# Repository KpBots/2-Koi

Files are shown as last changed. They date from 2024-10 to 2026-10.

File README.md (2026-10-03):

# 2-Koi · Mini-sumo

**2-Koi quedó segundo en la competición de mini-sumo de la OSHWDem 2024.** En esta ocasión se adapta su firmware a la [normativa de 2026](https://rules.oshwdem.org/loita_sumo_es): el juez inicia y detiene el robot por infrarrojos y el movimiento comienza sin la antigua espera de cinco segundos.

El programa se carga en un Arduino Nano con ATmega328P. El módulo IRStart recibe y decodifica el mando IR; el Nano solo lee el estado mantenido de su salida `OUT`. Por tanto, el IRStart debe tener ya cargados los códigos START y STOP adecuados. El programa del Nano no decodifica RC05 ni configura el módulo.

## Conexiones

| Componente | Pin del Nano | Uso |
| --- | --- | --- |
| Sensor de presencia | A0 | Medida analógica del oponente |
| IRStart VCC | A1 | Salida HIGH que alimenta el módulo |
| IRStart GND | A2 | Salida LOW que hace de masa |
| IRStart OUT | A3 | Entrada digital; LOW = parado, HIGH = activo |
| Sensor de borde izquierdo | D7 | Entrada activa en LOW |
| Sensor de borde derecho | D8 | Entrada activa en LOW |
| Selector derecho | D6 | Entrada con pull-up |
| Común de los selectores | D5 | Salida LOW |
| Selector frontal | D4 | Entrada con pull-up |
| Selector izquierdo | D2 | Entrada con pull-up |
| Motor izquierdo | D9 y D10 | Entradas del puente H |
| Motor derecho | D3 y D11 | Entradas del puente H |

Los selectores se activan al unir su entrada con el común D5. El interruptor izquierdo está montado con la orientación física inversa a la esperada: comprueba su posición por la maniobra que realiza, no por la marca ON/OFF de la carcasa. Para que un cable `OUT` suelto no deje A3 flotante, se puede añadir una resistencia externa de 10 kΩ entre A3 y GND.

## Elegir la estrategia de salida

Coloca los selectores **antes de enviar START**. El programa los lee al comenzar cada asalto. La maniobra inicial dura solo el tiempo indicado; después el robot pasa a buscar al oponente.

| Selectores activados | Primera maniobra tras START |
| --- | --- |
| Izquierdo + derecho | Retrocede 300 ms |
| Izquierdo | Gira sobre sí mismo a la izquierda 150 ms |
| Frontal | Avanza 150 ms |
| Derecho | Gira sobre sí mismo a la derecha 120 ms |
| Ninguno | Empieza a buscar inmediatamente |

Si activas varios selectores, la prioridad es: **izquierdo + derecho**, luego **izquierdo**, luego **frontal** y, por último, **derecho**. Por ejemplo, frontal + derecho ejecuta la salida frontal. El selector frontal no modifica la salida hacia atrás si están activados ambos laterales.

Durante la búsqueda, el robot avanza hacia un objeto detectado aproximadamente entre 20 y 200 mm. Si no detecta ninguno, alterna al azar giros a izquierda y derecha. El LED integrado del Nano se enciende mientras detecta al oponente. La maniobra inicial se completa antes de atender los sensores de borde; después, un sensor de borde activo tiene prioridad sobre la búsqueda: el robot retrocede 100 ms y gira para alejarse del borde. STOP sigue teniendo prioridad en todo momento.

## Arranque, parada y carga

1. Abre `2-Koi/2-Koi.ino` en Arduino IDE. Selecciona **Arduino Nano**, ATmega328P y el procesador/bootloader que corresponda a tu placa; después carga el programa por USB.
2. Para la primera prueba, levanta las ruedas del suelo. Enciende el robot con IRStart conectado: debe quedarse parado hasta recibir START. Si el Nano arranca cuando `OUT` ya está en HIGH, esperará a ver primero un estado LOW y luego otro START.
3. Ajusta los selectores y envía START con el mando del juez, un mando compatible o la app configurada para los códigos del IRStart. Observa las ruedas justo al arrancar: la estrategia solo dura entre 120 y 300 ms; después comienza la búsqueda.
4. Envía STOP mientras se mueve: los motores deben detenerse, incluso si está retrocediendo o girando por un borde. Un nuevo START inicia otra vez la estrategia seleccionada.
5. Antes de ponerlo en el dohyo, comprueba por separado los dos sensores de borde y que el LED del Nano responde al sensor de presencia. Haz la prueba de START/STOP con las ruedas levantadas cada vez que cambies el firmware.

El código no utiliza el puerto serie durante el combate. La señal `OUT` del IRStart es un nivel de marcha/parada, no una trama que haya que interpretar en el Nano.

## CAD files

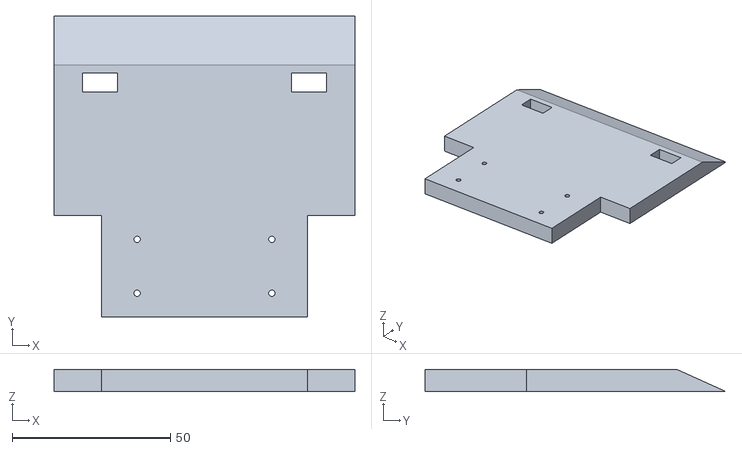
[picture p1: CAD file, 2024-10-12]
Archivos 3D/Molde 2koi.stl
95.0 x 95.0 x 7.00

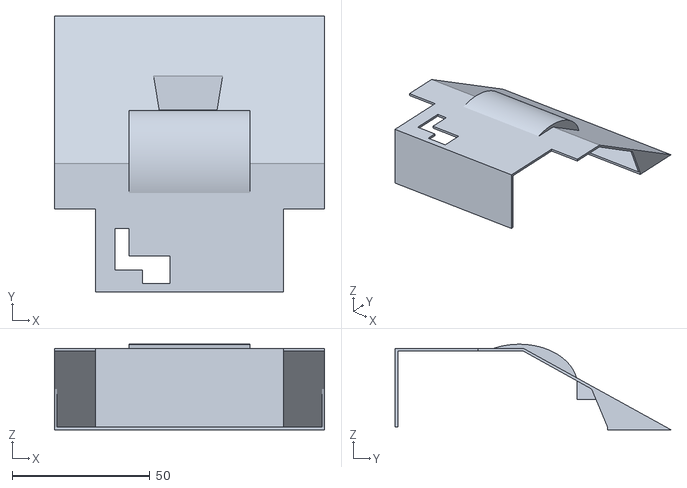
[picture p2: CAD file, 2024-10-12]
Archivos 3D/Cubierta sumo.stl
98.0 x 100.0 x 31.0

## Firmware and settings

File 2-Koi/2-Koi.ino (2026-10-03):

#include <Arduino.h>

// Sensor de presencia y sensores de borde (activos en LOW).
const uint8_t sensorPresence = A0;
const uint8_t sensorLeft = 7;
const uint8_t sensorRight = 8;

// IRStart: la placa recibe alimentacion de A1/A2 y entrega OUT en A3.
const uint8_t irVcc = A1;
const uint8_t irGnd = A2;
const uint8_t irOut = A3;

// Selectores de estrategia (activos en LOW).
const uint8_t switchRight = 6;
const uint8_t switchCommon = 5;
const uint8_t switchFront = 4;
const uint8_t switchLeft = 2;

// Entradas del puente H: motor izquierdo y motor derecho.
const uint8_t motorLeftA1B = 9;
const uint8_t motorLeftA1A = 10;
const uint8_t motorRightB1B = 3;
const uint8_t motorRightB1A = 11;

const unsigned long presenceSampleMs = 26UL;
const unsigned long goBackMs = 100UL;
const unsigned long turnLeftMs = 150UL;
const unsigned long turnRightMs = 120UL;

enum MotionState : uint8_t {
  WAIT_FOR_START,
  OPENING,
  EDGE_BACK,
  EDGE_TURN,
  SEARCH
};

MotionState motionState = WAIT_FOR_START;
unsigned long stateStartedAt = 0UL;
unsigned long stateDurationMs = 0UL;
unsigned long lastPresenceSampleAt = 0UL;
unsigned long wanderStartedAt = 0UL;
unsigned long wanderDurationMs = 0UL;
bool startArmed = false;
bool presenceSampleValid = false;
bool opponentPresent = false;
bool wandering = false;
bool leftEdgeAtStart = false;
bool rightEdgeAtStart = false;

float distance(int raw);
void enterSearch();
void beginOpening(unsigned long now);
void beginEdgeRecovery(unsigned long now, bool leftEdge, bool rightEdge);
void updateEdgeRecovery(unsigned long now);
void updateSearch(unsigned long now);

void setup() {
  // Primero aseguramos que los motores esten parados.
  pinMode(motorLeftA1B, OUTPUT);
  pinMode(motorLeftA1A, OUTPUT);
  pinMode(motorRightB1B, OUTPUT);
  pinMode(motorRightB1A, OUTPUT);
  motorsStop();

  pinMode(LED_BUILTIN, OUTPUT);
  digitalWrite(LED_BUILTIN, LOW);

  pinMode(sensorPresence, INPUT);
  pinMode(sensorLeft, INPUT);
  pinMode(sensorRight, INPUT);

  pinMode(switchRight, INPUT_PULLUP);
  pinMode(switchFront, INPUT_PULLUP);
  pinMode(switchLeft, INPUT_PULLUP);
  digitalWrite(switchCommon, LOW);
  pinMode(switchCommon, OUTPUT);

  // Preparamos el nivel antes de poner A1/A2 como salidas para evitar pulsos.
  digitalWrite(irVcc, HIGH);
  pinMode(irVcc, OUTPUT);
  digitalWrite(irGnd, LOW);
  pinMode(irGnd, OUTPUT);
  pinMode(irOut, INPUT);
}

void loop() {
  const unsigned long now = millis();

  // OUT del IRStart es un nivel mantenido. STOP tiene prioridad absoluta.
  if (digitalRead(irOut) == LOW) {
    startArmed = true; // Exigimos haber visto reposo antes del primer START.
    if (motionState != WAIT_FOR_START) {
      motorsStop();
      motionState = WAIT_FOR_START;
    }
    digitalWrite(LED_BUILTIN, LOW);
    return;
  }
  if (!startArmed) {
    // Un Nano que reinicia con OUT ya alto permanece parado hasta un nuevo ciclo.
    return;
  }

  if (motionState == WAIT_FOR_START) {
    beginOpening(now);
  }

  // La maniobra inicial se completa antes de atender los sensores de borde.
  // STOP se comprueba arriba en cada vuelta, tambien durante esta maniobra.
  if (motionState == OPENING) {
    if (now - stateStartedAt < stateDurationMs) return;
    enterSearch();
  }

  if (motionState == EDGE_BACK || motionState == EDGE_TURN) {
    updateEdgeRecovery(now);
    return;
  }

  const bool leftEdge = digitalRead(sensorLeft) == LOW;
  const bool rightEdge = digitalRead(sensorRight) == LOW;
  if (leftEdge || rightEdge) {
    beginEdgeRecovery(now, leftEdge, rightEdge);
    return;
  }

  updateSearch(now);
}

void enterSearch() {
  motionState = SEARCH;
  presenceSampleValid = false;
  wandering = false;
  motorsStop();
}

void beginOpening(unsigned long now) {
  stateStartedAt = now;
  motionState = OPENING;
  digitalWrite(LED_BUILTIN, LOW);

  if (digitalRead(switchLeft) == LOW) {
    if (digitalRead(switchRight) == LOW) {
      // Ambos selectores laterales: salida hacia atras.
      stateDurationMs = turnLeftMs * 2UL;
      motorsMoveBackwards();
    } else {
      stateDurationMs = turnLeftMs;
      motorsRotateLeft();
    }
  } else if (digitalRead(switchFront) == LOW) {
    stateDurationMs = turnLeftMs;
    motorsMoveForward();
  } else if (digitalRead(switchRight) == LOW) {
    stateDurationMs = turnRightMs;
    motorsRotateRight();
  } else {
    enterSearch();
  }
}

void beginEdgeRecovery(unsigned long now, bool leftEdge, bool rightEdge) {
  leftEdgeAtStart = leftEdge;
  rightEdgeAtStart = rightEdge;
  stateStartedAt = now;
  motionState = EDGE_BACK;
  digitalWrite(LED_BUILTIN, LOW);
  motorsMoveBackwards();
}

void updateEdgeRecovery(unsigned long now) {
  if (motionState == EDGE_BACK) {
    if (now - stateStartedAt < goBackMs) return;

    if (rightEdgeAtStart && !leftEdgeAtStart) {
      stateDurationMs = turnLeftMs;
      motorsTurnLeft();
    } else if (leftEdgeAtStart && !rightEdgeAtStart) {
      stateDurationMs = turnRightMs;
      motorsTurnRight();
    } else {
      stateDurationMs = turnLeftMs;
      motorsRotateLeft();
    }
    stateStartedAt = now;
    motionState = EDGE_TURN;
    return;
  }

  if (now - stateStartedAt >= stateDurationMs) {
    enterSearch();
  }
}

void updateSearch(unsigned long now) {
  // El sensor de presencia entrega una medida nueva cada ~25,2 ms.
  if (!presenceSampleValid || now - lastPresenceSampleAt >= presenceSampleMs) {
    const float measuredDistance = distance(analogRead(sensorPresence));
    opponentPresent = measuredDistance > 20.0f && measuredDistance <= 200.0f;
    lastPresenceSampleAt = now;
    presenceSampleValid = true;
  }

  if (opponentPresent) {
    motorsMoveForward();
    digitalWrite(LED_BUILTIN, HIGH);
    wandering = false;
    return;
  }

  digitalWrite(LED_BUILTIN, LOW);
  if (!wandering || now - wanderStartedAt >= wanderDurationMs) {
    switch (random(0, 4)) {
      case 0: motorsTurnLeft(); break;
      case 1: motorsTurnRight(); break;
      case 2: motorsRotateLeft(); break;
      case 3: motorsRotateRight(); break;
    }
    wanderStartedAt = now;
    wanderDurationMs = random(100UL, 300UL);
    wandering = true;
  }
}

// Conversion de la tension del sensor de presencia a distancia en mm.
float distance(int raw) {
  const float voltage = (5.0f * raw) / 1024.0f;
  const float a = 48.375f;
  const float b = 0.0675f;
  return voltage > b ? a / (voltage - b) : 0.0f;
}

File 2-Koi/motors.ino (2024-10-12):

void motorsMoveForward(){
  analogWrite(motorLeftA1A, 0);
  analogWrite(motorLeftA1B, 255);
  analogWrite(motorRightB1A, 0);
  analogWrite(motorRightB1B, 255);
}

void motorsMoveBackwards() {
  analogWrite(motorLeftA1A, 255);
  analogWrite(motorLeftA1B, 0);
  analogWrite(motorRightB1A, 255);
  analogWrite(motorRightB1B, 0);
}

void motorsTurnLeft() {
  analogWrite(motorLeftA1A, 0);
  analogWrite(motorLeftA1B, 0);
  analogWrite(motorRightB1A, 0);
  analogWrite(motorRightB1B, 255);
}

void motorsTurnRight() {
  analogWrite(motorLeftA1A, 0);
  analogWrite(motorLeftA1B, 255);
  analogWrite(motorRightB1A, 0);
  analogWrite(motorRightB1B, 0);
}

void motorsRotateLeft() {
  analogWrite(motorLeftA1A, 255);
  analogWrite(motorLeftA1B, 0);
  analogWrite(motorRightB1A, 0);
  analogWrite(motorRightB1B, 255);
}

void motorsRotateRight() {
  analogWrite(motorLeftA1A, 0);
  analogWrite(motorLeftA1B, 255);
  analogWrite(motorRightB1A, 255);
  analogWrite(motorRightB1B, 0);
}

void motorsStop() {
  analogWrite(motorLeftA1A, 0);
  analogWrite(motorLeftA1B, 0);
  analogWrite(motorRightB1A, 0);
  analogWrite(motorRightB1B, 0);
}

void motorsMoveCustom(int A1A, int A1B, int B1A, int B1B) {
  analogWrite(motorLeftA1A, A1A);
  analogWrite(motorLeftA1B, A1B);
  analogWrite(motorRightB1A, B1A);
  analogWrite(motorRightB1B, B1B);
}
